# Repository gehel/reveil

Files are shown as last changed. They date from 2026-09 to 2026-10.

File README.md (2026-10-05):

# Réveil pour sourd

> **Statut : en cours de développement**

Réveil électronique custom conçu pour les personnes sourdes ou malentendantes. Au lieu d'une alarme sonore, le réveil utilise une LED clignotante et un moteur vibrant pour réveiller l'utilisateur.

## Matériel

### Microcontrôleur
- **Raspberry Pi Pico W** (RP2040) — firmware CircuitPython

### Affichages
- **2× MAX7219** pilotant 4 affichages 7-segments de 4 chiffres chacun :
  - Affichage de la date (jour/mois)
  - Affichage de l'année
  - Affichage de l'heure courante
  - Affichage de l'heure d'alarme

### Contrôles

| Composant | Rôle |
|---|---|
| 3× encodeurs rotatifs | Réglage de la date/année, de l'heure, et de l'alarme |
| Bouton poussoir | Arrêt de l'alarme |
| Interrupteur SPDT | Activation / désactivation de l'alarme |
| Bouton poussoir | Allumage des affichages et LED (extinction automatique après 30 s d'inactivité) |
| Potentiomètre | Réglage de la luminosité des affichages 7-segments |

### Alarme
- **LED** blanche (D1) clignotante, pilotée via un transistor Q1 (2N3904)
- **Moteur DC** piloté via un MOSFET (Q2) pour faire vibrer le lit — **IRLB8721PbF** (logic-level) dans le schéma/PCB, avec une résistance de grille R5 (100 Ω) ; la carte physique a encore l'ancien **IRF510** sans résistance de grille, rework pas encore fait (voir TODO)

### Alimentation
- Port **USB** du Raspberry Pi Pico
- **Barrel jack** 5 V (alternatif)

## Fichiers KiCad

Les fichiers source KiCad sont à la racine du projet :

| Fichier | Contenu |
|---|---|
| `reveil.kicad_sch` | Schématique racine |
| `heure_alarme.kicad_sch` | Feuille *Heure et Alarme* |
| `date.kicad_sch` | Feuille *Date* |
| `reveil.kicad_pcb` | Layout PCB |
| `fp-lib-table` | Table de librairies de footprints du projet (référence `reveil.pretty/`) |
| `reveil.pretty/` | Librairie locale de footprints corrigés (overrides de footprints système erronés — voir TODO) |

### Générer les fichiers Gerber avec KiBot

Les fichiers de fabrication (Gerber, BOM, positions) sont générés via [KiBot](https://github.com/INTI-CMNB/KiBot) à partir de `config.kibot.yaml`. `kibot` nécessite `wxPython` (pas de wheel précompilé sur toutes les plateformes) — utiliser le conteneur Docker de la CI plutôt qu'un `pip install` local :

```bash
docker run --rm -v "$PWD":/mnt -w /mnt ghcr.io/inti-cmnb/kicad9_auto_full:latest kibot -c config.kibot.yaml
```

`kicad-cli` (ERC/DRC en ligne de commande) est fourni par l'installation KiCad elle-même — via le snap, il est accessible en `/snap/bin/kicad.kicad-cli` (pas `kicad-cli` directement sur le PATH).

Les fichiers générés se trouvent dans le dossier `Generated/`. Les fichiers prêts pour JLCPCB sont dans `jlcpcb/`.

### Skills Claude Code (kicad-happy)

Les skills [kicad-happy](https://github.com/aklofas/kicad-happy) (analyse schéma/PCB, BOM, datasheets, EMC, SPICE, fournisseurs JLCPCB/LCSC/DigiKey/Mouser…) sont installés au niveau du projet via [`skills`](https://github.com/vercel-labs/skills) :

```bash
npx skills add aklofas/kicad-happy
```

Seul `skills-lock.json` (sources et hashes des skills) est versionné ; les fichiers installés (`.agents/skills/`, et les liens symboliques `.claude/skills/`) sont ignorés par git. Pour les restaurer après un clone, ou les mettre à jour :

```bash
npx skills experimental_install   # restaure les skills depuis skills-lock.json
npx skills update -p               # met à jour les skills du projet (et skills-lock.json)
```

## Connexions (RP2040)

| GPIO | Composant | Signal |
|---|---|---|
| GP0  | Encodeur *Heure* | A |
| GP1  | Encodeur *Heure* | B |
| GP2  | Encodeur *Heure* | SW (bouton) |
| GP3  | Encodeur *Date/Année* | A |
| GP4  | Encodeur *Date/Année* | B |
| GP5  | MAX7219 *Heure/Alarme* | CS (LOAD) |
| GP6  | MAX7219 *Heure/Alarme* | CLK |
| GP7  | MAX7219 *Heure/Alarme* | DIN |
| GP8  | Encodeur *Date/Année* | SW (bouton) |
| GP9  | MAX7219 *Date/Année* | CS (LOAD) |
| GP10 | MAX7219 *Date/Année* | CLK |
| GP11 | MAX7219 *Date/Année* | DIN |
| GP12 | Encodeur *Alarme* | A |
| GP13 | Encodeur *Alarme* | B |
| GP14 | Encodeur *Alarme* | SW (bouton) |
| GP15 | Bouton allumage affichages | Signal |
| GP16 | Bouton arrêt alarme | Signal |
| GP17 | LED alarme | Signal |
| GP18 | MOSFET moteur DC (Q2) | Gate |
| GP19 | Interrupteur SPDT alarme | Signal |
| GP26 | Potentiomètre luminosité | ADC |

## Logiciel

Firmware écrit en **CircuitPython**. Point d'entrée : `firmware/code.py`. La logique est dans `firmware/reveil/` :
- `firmware/reveil/display.py` — pilotage des 2 puces MAX7219 (classe `Afficheurs`)
- `firmware/reveil/encoder.py` — encodeur rotatif + bouton associé (classe `Encodeur`)
- `firmware/reveil/reglage_date.py` — logique pure du réglage date/année (cycle de modes, calcul des jours par mois, application d'une rotation) : aucune dépendance matérielle, testable directement sur l'hôte
- `firmware/reveil/reglage_heure.py` — logique pure du réglage heure (cycle de modes, application d'une rotation sur heures/minutes) : même principe que `reglage_date.py`, réutilisé tel quel pour l'heure d'alarme
- `firmware/reveil/luminosite.py` — lecture du potentiomètre LUMINOSITE (classe `Potentiometre`) + conversion pure ADC→niveau MAX7219 (`niveau_depuis_adc()`)

`display.py`, `encoder.py` et `luminosite.py` séparent la construction matérielle (`depuis_broches()`/`depuis_broche()`, qui importent `board`/`busio`/`digitalio`/`rotaryio`/`analogio`) du reste de la classe, qui reçoit ses dépendances déjà construites — ça permet de tester leur logique (calcul de delta, détection de clic, écriture des digits, conversion ADC) avec de faux objets, sans Pico ni stubs CircuitPython. `code.py` déploie via ces méthodes ; les tests injectent de faux capteurs/chips (voir `firmware/tests/`).

`make deploy` copie `firmware/code.py` et aplatit `firmware/reveil/*.py` à la racine de `CIRCUITPY` (CircuitPython ne cherche les modules qu'à la racine et dans `lib/`, pas dans un sous-dossier arbitraire du dépôt).

### Mode de fonctionnement

**Affichages DATE et ANNEE.** En fonctionnement normal, l'affichage DATE montre le jour et le mois courants au format `JJ.MM` (point décimal séparateur entre les deux), et l'affichage ANNEE montre l'année sur 4 chiffres. Les valeurs viennent de l'horloge interne du RP2040 (module CircuitPython `rtc`) : celle-ci n'a **pas de pile de sauvegarde** sur cette carte, donc elle repart d'une date par défaut (1er janvier de l'année courante de développement) à chaque reset ou coupure d'alimentation — elle doit être réglée à nouveau à chaque démarrage.

**Réglage via l'encodeur REGLAGE_DATE.** Un clic sur le bouton de l'encodeur fait entrer/avancer dans le cycle de réglage :

1. Appui 1 → mode **réglage du jour** : le champ jour clignote (~1,25 Hz), tourner l'encodeur l'incrémente/décrémente (boucle 1 → dernier jour du mois → 1, en tenant compte des mois à 30/31 jours et des années bissextiles).
2. Appui 2 → mode **réglage du mois** : le champ mois clignote, rotation = incrément/décrément (boucle 1-12). Si le jour courant n'existe pas dans le nouveau mois (ex. 31 → février), il est ramené au dernier jour valide.
3. Appui 3 → mode **réglage de l'année** : l'affichage ANNEE clignote en entier, rotation = incrément/décrément (boucle 2000-2099). Même ajustement du jour si nécessaire (29 février d'une année non bissextile).
4. Appui 4 → retour au mode **normal** (plus aucun champ ne clignote), le cycle recommence au prochain clic.

Chaque changement de valeur est appliqué immédiatement à l'horloge RTC (pas de bouton "valider" séparé).

**Affichage HEURE.** En fonctionnement normal, montre l'heure courante au format `HH.MM` (point décimal séparateur). Même horloge RTC que DATE/ANNEE (pas de pile de sauvegarde, à régler à chaque démarrage).

**Réglage via l'encodeur REGLAGE_HEURE.** Cycle à 3 états (un champ de moins que REGLAGE_DATE, pas d'équivalent de l'année) :

1. Appui 1 → mode **réglage des heures** : le champ heures clignote, rotation = incrément/décrément (boucle 0-23).
2. Appui 2 → mode **réglage des minutes** : le champ minutes clignote, rotation = incrément/décrément (boucle 0-59).
3. Appui 3 → retour au mode **normal**, le cycle recommence au prochain clic.

Même principe que REGLAGE_DATE : chaque changement est appliqué immédiatement à l'horloge RTC.

**Affichage ALARME.** Montre l'heure d'alarme réglée, au format `HH.MM`. Contrairement à DATE/ANNEE/HEURE, ce n'est **pas** une valeur RTC : juste une paire (heures, minutes) gardée en mémoire côté firmware, réinitialisée à une valeur par défaut (7h00) à chaque démarrage — comme pour l'heure courante, il n'y a pas de pile de sauvegarde.

**Réglage via l'encodeur REGLAGE_ALARME.** Même cycle à 3 états que REGLAGE_HEURE (réglage des heures puis des minutes de l'alarme, mêmes bornes 0-23/0-59), avec les mêmes fonctions de logique (`reglage_heure.py` est réutilisé tel quel : une paire heures/minutes avec un cycle de réglage à 2 champs, que ce soit l'heure courante ou l'heure d'alarme).

**L'alarme ne se déclenche pas encore** : pas de comparaison avec l'heure courante, pas de pilotage de la LED ni du moteur. Seule l'heure d'alarme peut être affichée et réglée pour l'instant.

**Luminosité via le potentiomètre LUMINOSITE.** Lu en continu (à chaque itération de la boucle principale) et appliqué aux deux puces MAX7219 (donc aux 4 affichages). La valeur ADC brute (0-65535) est convertie en niveau MAX7219 (0-15) par `luminosite.niveau_depuis_adc()`.

**Pas encore géré par ce firmware** : déclenchement de l'alarme (LED, moteur), bouton d'allumage des affichages, bouton d'arrêt alarme, interrupteur SPDT — voir TODO.

### Dépendances

Les bibliothèques CircuitPython nécessaires sont listées dans `firmware/requirements.txt` :

```
adafruit_max7219
```

Copier les bibliothèques dans le dossier `lib/` du Pico (accessible en mode stockage USB), ou via `make deps` (voir `firmware/Makefile`).

## TODO

### Problèmes matériels connus
- [x] ~~Court-circuit GND/+3V3 via l'interrupteur `ALARME_ON_OFF1` : le footprint système (`Button_Switch_THT:SW_Slide-03_Wuerth-WS-SLTV...`) avait les pads 1 et 2 physiquement inversés par rapport au composant monté.~~ Corrigé via une librairie locale `reveil.pretty/` (pads 1/2 échangés) + `fp-lib-table`. Vérifié par mesure au multimètre, ERC et DRC (voir historique git).
- [x] ~~LED D1 toujours allumée faiblement au lieu de clignoter : la base de Q1 (2N3904, driver de D1) était câblée directement sur GP17 sans résistance série, empêchant GP17 d'atteindre un état haut propre (chargé par la jonction base-émetteur).~~ Corrigé dans KiCad : ajout de **R4 = 1.5 kΩ** en série sur la base, et **R3 = 100 Ω** (au lieu de 47 kΩ, qui aurait quasi éteint la LED) pour ~16 mA dans D1 (LED blanche, Vf≈3.2V supposé — pas de référence/datasheet exacte pour D1, à vérifier si besoin de précision). Vérifié par ERC/DRC.
  - [ ] **Bloquant pour tester la LED** : le PCB physique existant n'a pas ces corrections (footprint switch + R3/R4) — il faut ressouder à la main (bodge) ou fabriquer un nouveau PCB avant de pouvoir tester `code.py` avec `board.LED` remplacé par `board.GP17`. `firmware/code.py` a été remis à `board.LED` (LED embarquée du Pico) en attendant.
- [x] ~~**Décalage schéma/carte physique — Q2 (moteur DC)** : le schéma KiCad indiquait un IRF540N, mais le MOSFET réellement monté sur le PCB physique était un IRF510.~~ Résolu en remplaçant Q2 par un **IRLB8721PbF** (logic-level) dans le schéma et le PCB — voir point suivant, qui couvre aussi la raison de ce changement. Footprint `TO-220-3_Horizontal_TabDown` (corrigé après repérage d'une variante `TO-220F` erronée), pinout G/D/S broches 1/2/3 vérifié contre la convention IR/Infineon. Vérifié par ERC/DRC.
- [x] ~~**Pilotage de grille de Q2 (moteur DC)** : topologie de câblage correcte (Gate←GP18, Drain→moteur(-), Source→GND, moteur(+)→VBUS ; vérifié via l'analyse du netlist). Le problème identifié :~~
  - GP18 pilote la grille de Q2 directement en 3.3V, sans résistance de grille ni driver dédié.
  - Ni l'IRF540N (ancien schéma) ni l'IRF510 (carte physique) ne sont des MOSFET **"logic-level"** : leur Rds(on) nominal est spécifié à Vgs=10V (IRF510 : ~0.54Ω max ; IRF540N : ~44-77 mΩ). À 3.3V (Vgs proche du seuil typique 2-4V de ces composants), le MOSFET risque de ne pas être pleinement enhancé → Rds(on) effectif bien plus élevé que la valeur datasheet → échauffement de Q2 et/ou sous-alimentation du moteur.
  - Corrigé dans KiCad : Q2 remplacé par un **IRLB8721PbF** (Vgs(th) ≈ 1-2V, pleinement enhancé dès Vgs≈2.5V, Rds(on) ≈ 8.7 mΩ typique à Vgs=4.5V — largement suffisant en pilotage direct 3.3V), plus ajout de **R5 = 100 Ω** en série sur la grille (limite le pic de courant transitoire vu par GP18 et amortit le ringing). Vérifié par ERC/DRC.
  - [ ] **Bloquant pour tester le moteur** : le PCB physique existant a encore l'ancien IRF510 sans R5 — il faut ressouder à la main (bodge) ou fabriquer un nouveau PCB avant de pouvoir tester le moteur avec ce circuit. Un moteur de test n'est de toute façon pas encore disponible.

### Améliorations matérielles proposées (revue schéma/PCB du 2026-10-03)

État au moment de la revue : ERC 0 erreur / 0 avertissement ; DRC 0 piste non connectée, 0 écart schéma/PCB, seulement 6 avertissements de sérigraphie de J2 coupée par le bord (normal pour un jack en bordure). Limite de la revue : aucun composant n'a de MPN ni de datasheet dans le projet, les valeurs datasheet citées ci-dessous n'ont pas été relues dans les PDF.

**Prioritaire**
- [x] ~~**Symbole des afficheurs incohérent avec le câblage** : le schéma utilisait `CA56-12EWA` (anode commune), mais les anodes communes CA1-CA4 sont reliées aux sorties `DIG_x` du MAX7219 (qui *absorbent* le courant) et les segments aux sorties `SEG_x` (qui *fournissent* le courant). Avec de vrais afficheurs à anode commune, rien ne s'allumerait ; comme les afficheurs fonctionnent, les composants montés sont très probablement à cathode commune (confirmé par le fonctionnement du circuit, référence imprimée non relue).~~ → Symbole remplacé par `CC56-12EWA` (même brochage/footprint `Display_7Segment:CA56-12EWA`, seules la doc et la BOM changent) dans `date.kicad_sch`, `heure_alarme.kicad_sch` et la `Value` des empreintes dans `reveil.kicad_pcb`. BOM/CPL JLCPCB (`jlcpcb/production_files/`) encore à régénérer via `kibot -c config.kibot.yaml` (kibot non disponible dans cet environnement).
- [x] ~~**Pas de diode de roue libre sur le moteur** : rien entre le drain de Q2 et VBUS, en parallèle de M1. La surtension inductive à chaque coupure passe par l'avalanche de Q2 et parasite le 5 V du Pico.~~ → Ajouté en schéma : D2 (Schottky 1N5819, cathode côté VBUS, anode côté drain de Q2) et C5 (100 nF) en parallèle de M1. Reste à faire : `update PCB from schematic` et placement manuel des empreintes D2/C5 sur le PCB avant fabrication (pas d'empreinte existante pour ces deux nouveaux composants).
- [x] ~~**Grille de Q2 flottante au démarrage** : GPIO18 est en haute impédance pendant le boot/reset → vibration intempestive possible, ou Q2 à moitié passant qui chauffe.~~ → Ajouté R6 (100 kΩ) entre grille et source de Q2, près de Q2 ; ajouté aussi R7 (47 kΩ) entre base et émetteur de Q1, pour garder Q1 déterministement bloqué. Empreintes placées et routées sur le PCB.
- [x] ~~**R1 sans valeur** (valeur « R ») : c'est la résistance ISET de U2.~~ → Mis à 47 kΩ comme R2 (≈ 14 mA par segment), sinon HEURE/ALARME n'auraient pas eu la même luminosité que DATE/ANNEE.

**Alimentation**
- [x] ~~**Le barrel jack J1 alimente directement VBUS** : si l'USB est branché en même temps, les deux 5 V sont en parallèle et l'alimentation du jack renvoie du courant vers le PC.~~ → Ajouté en schéma/PCB : **D3** (Schottky 1N5822, anode côté jack, cathode côté rail) et **C6** (220 µF) en entrée du jack, le rail résultant renommé **VSYS** (branché sur la broche VSYS/39 du Pico, plus sur VBUS/40). Tout ce qui était sur l'ancien net VBUS (MAX7219 U1/U2, moteur, LED, D2) est maintenant sur VSYS ; la broche VBUS du Pico (40) n'est plus connectée côté carte, elle ne sert plus qu'à l'alimentation USB du Pico lui-même. Vérifié par analyse du schéma et du netlist PCB (kibot non disponible dans cet environnement, DRC/ERC à relancer avant fabrication). Reste à faire : pas de protection contre l'inversion de polarité du jack ; le PCB physique existant n'a ni D3 ni C6 (nouveau PCB ou bodge nécessaire avant de tester l'alimentation par jack).
- [ ] **Logique 3,3 V vers un MAX7219 alimenté en 5 V** : le VIH minimal du MAX7219 est de 3,5 V, les signaux du Pico sont hors spécification (ça marche, mais sans marge). → 74AHCT125 ou 74HCT245 alimenté en 5 V sur DIN/CLK/LOAD (6 signaux).
- [ ] **Découplage des MAX7219 trop loin** (datasheet : 10 µF + 100 nF au plus près de V+/GND). Distances estimées depuis la broche V+ : U1 → C1 ≈ 21 mm, C2 ≈ 30 mm ; U2 → C3 ≈ 12 mm, C4 ≈ 15 mm. → Rapprocher à moins de 5 mm (le balayage du MAX7219 crée de forts pics de courant).

**PCB**
- [ ] Toutes les pistes font 0,2 mm, alimentations comprises. → Passer VBUS, GND et le chemin moteur (drain de Q2) à 0,5-1 mm.
- [ ] Plan de masse B.Cu très découpé par les pistes de signal. → Ajouter des vias de couture GND, router moins en B.Cu.
- [x] ~~VIBREUR fait ≈ 169 mm entre le Pico et Q2.~~ → Garder R5 et la future résistance de rappel près de Q2 (déjà le cas pour R5). C'est fait : R5 (~20 mm de Q2) et R6 (~5.5 mm de Q2, ajoutée avec la correction de la grille flottante) sont les deux près de Q2 ; les 169 mm sont juste le signal GP18 brut entre le Pico et R5, sans caractère critique.
- [ ] Cartouche vide (titre, révision, date) sur le schéma et le PCB. → Le remplir (les sorties KiBot en profitent).
- [ ] Ajouter des points de test (voir section suivante).

**Fonctionnel**
- [ ] **Aucune sauvegarde de l'heure** : une coupure de courant efface l'heure et l'alarme, ce qui est critique pour un réveil. → DS3231 + pile CR2032 sur I2C (GP20/GP21 sont libres), et/ou synchronisation NTP par le WiFi du Pico W (firmware seul).
- [ ] **Une LED 3 mm (~16 mA) réveille mal.** → LED de puissance ou ruban LED commandé par un MOSFET, comme le moteur.
- [ ] **Moteur sur un jack 3,5 mm avec le +5 V sur le manchon** (exposé). → Connecteur polarisé et verrouillable (JST-XH, bornier).
- [x] ~~Pour M1, cocher « Exclure du PCB » plutôt que de laisser l'empreinte vide.~~ Déjà fait : M1 a `on_board no` dans le schéma et aucune empreinte dans le PCB.
- [x] ~~100 nF sur le curseur de LUMINOSITE, alimenté par ADC_VREF/AGND.~~ → Ajouté **C7** (100 nF) sur le curseur, et le haut du potentiomètre LUMINOSITE1 reconnecté sur **ADC_VREF** (broche du Pico, auparavant non connectée) au lieu de +3V3. Empreintes placées et routées sur le PCB.
- [x] ~~Bouton reset (RUN vers GND) pour le développement.~~ Pas voulu : décision du mainteneur, pas de bouton reset.
- [x] ~~Filtres RC pour les encodeurs EC11 (10 kΩ + 10 nF).~~ Pas nécessaire pour l'instant : les encodeurs fonctionnent suffisamment bien sans, à revoir si besoin plus tard.

**Faux positifs écartés par la revue** : 3V3_EN « sans pull-up » (pull-up interne au Pico), J2 « sans masse » (moteur commuté côté bas, voulu), absence de MPN (sans importance pour un montage à la main), J2 qui dépasse du bord (montage en bordure).

### Points de test proposés

Pastilles traversantes (`TestPoint:TestPoint_THTPad_D2.0mm_Drill1.0mm`) ou boucles (`TestPoint:TestPoint_Keystone_5000-5004_Miniature`) pour les masses, avec la référence `TPx` et le nom du net sur la sérigraphie. À placer en bord de carte ou dans les zones dégagées, accessibles avec les afficheurs et les encodeurs montés.

| Point | Net | Usage |
|---|-----|---|
| TP1, TP2, TP3 | GND | Masse pour la pince de l'oscilloscope / du multimètre : une près de J1, une près des MAX7219, une près de Q2 (boucles) |
| TP4 | VBUS (5 V, broche 40 du Pico) | Présent seulement si le Pico est alimenté par USB ; n'est plus relié au jack J1 (voir « Alimentation » ci-dessus) |
| TP5 | +3V3 | Sortie du régulateur du Pico |
| TP6 | VSYS | Tension d'entrée réelle (USB ou jack via D3), chute sous charge (moteur + afficheurs à fond) |
| TP7, TP8, TP9 | DATE_DIN, DATE_CLK, DATE_LOAD | Trame SPI vers U1 (niveaux logiques, décodage à l'analyseur logique) |
| TP10, TP11, TP12 | HEURE_ALARME_DIN, HEURE_ALARME_CLK, HEURE_ALARME_LOAD | Trame SPI vers U2 |
| TP13 | Grille de Q2 (après R5) | Commande du moteur, état au démarrage (vérifie la résistance de rappel) |
| TP14 | Drain de Q2 | Surtension de coupure du moteur (vérifie la diode de roue libre), Vds en conduction |
| TP15 | Collecteur de Q1 | Commande de la LED (saturation de Q1) |
| TP16 | LUMINOSITE | Tension du curseur du potentiomètre (bruit lu par l'ADC) |
| TP17 | ISET de U1 ou U2 | Optionnel : contrôle de la résistance ISET sans dessouder |

Les signaux des encodeurs, des boutons et de l'interrupteur restent accessibles directement sur les broches des composants, pas besoin de points de test dédiés.

### Structure du firmware
- [x] ~~`reveil/display.py`, `reveil/encoder.py`, `reveil/luminosite.py`~~ — modules matériels (MAX7219, encodeurs rotatifs, potentiomètre ADC), construction hardware isolée dans `depuis_broches()`/`depuis_broche()` pour rester testables par injection de dépendances
- [x] ~~`reveil/reglage_date.py`, `reveil/reglage_heure.py`~~ — logique métier des réglages date/année et heure, isolée (modules purs, sans import CircuitPython). `reglage_heure.py` est réutilisé tel quel pour l'heure d'alarme (même forme : une paire heures/minutes avec un cycle de réglage à 2 champs)
- [ ] `alarm.py` — déclenchement de l'alarme (comparaison heure courante / heure d'alarme réglée, pilotage LED + moteur) pas encore implémenté ; l'heure d'alarme peut déjà être affichée et réglée
- [ ] `backlight.py` — extinction automatique des affichages après 30 s d'inactivité pas encore implémentée (luminosité l'est déjà via `luminosite.py`, mais l'allumage/extinction sur bouton est distinct)
- [ ] Isoler la logique métier restante (déclenchement alarme, extinction auto) au fur et à mesure qu'elle est écrite, sur le même modèle que `reglage_date.py`

### Déploiement (Makefile)
- [x] ~~Créer un `Makefile` (`firmware/Makefile`) avec les cibles :~~
  - `make install-circuitpython` — flashe CircuitPython sur le Pico
  - `make deploy` — copie `code.py` et aplatit `reveil/*.py` à la racine du volume `CIRCUITPY` monté par l'hôte (pas `mpremote fs cp`, qui échoue en lecture seule sur CircuitPython)
  - `make deps` — installe les dépendances CircuitPython via `circup`
  - [x] ~~`make test-unit`~~ — lance les tests unitaires sur l'hôte (`pytest tests/`)
  - [ ] `make test-integration` — lance les tests d'intégration sur le Pico via `mpremote run` (cible stub, pas encore exécutable)
- [x] ~~Séparer les dépendances~~ : `firmware/requirements.txt` (librairies CircuitPython installées sur le Pico via `circup`, ce n'est pas un fichier pip) vs `requirements-dev.txt` à la racine (outillage hôte : `circup`, `pytest`, stubs d'autocomplete ; `kibot` nécessite Docker, voir commentaire dans le fichier)
- [ ] Envisager une migration vers Poetry (ou un outil équivalent) pour `requirements-dev.txt` si le besoin de lockfile reproductible ou de gestion d'environnement plus poussée se fait sentir — pas nécessaire pour l'instant (projet hobby solo, peu de dépendances)

### Tests unitaires (sur hôte)
- [x] ~~Mettre en place `pytest`~~ (`firmware/pytest.ini`, `firmware/tests/`, lancés via `make test-unit`)
- [x] ~~Écrire des stubs pour les modules CircuitPython~~ — évité par un autre moyen : `display.py`/`encoder.py`/`luminosite.py` séparent la construction matérielle (`depuis_broches()`/`depuis_broche()`) du reste de la classe, qui reçoit ses dépendances déjà construites (`board`/`busio`/`digitalio`/`rotaryio`/`analogio` ne sont importés que dans ces méthodes) ; les tests injectent de faux objets (voir `firmware/tests/test_display.py`, `test_encoder.py`, `test_luminosite.py`) sans avoir besoin de stubber les modules CircuitPython eux-mêmes
  - **Piège rencontré** : `firmware/code.py` (imposé par CircuitPython comme nom de point d'entrée) entre en collision avec le module standard `code` — si `firmware/` se retrouve dans `sys.path` (ex. `python -m pytest`, qui ajoute le répertoire courant), l'import de `code` par `pdb` récupère `firmware/code.py` à la place et plante. D'où `firmware/reveil/` comme dossier séparé pour la logique importable, et `pytest` invoqué directement (jamais `python -m pytest`) dans le Makefile.
- [x] ~~Écrire les tests unitaires pour la logique métier des réglages date/année et heure (`firmware/tests/test_reglage_date.py`, `test_reglage_heure.py`, réutilisés pour l'heure d'alarme) et pour la conversion ADC→luminosité (`test_luminosite.py`)~~ ; reste à faire au fur et à mesure pour le déclenchement de l'alarme, l'extinction automatique
- [x] ~~Test de régression sur la position physique 4-7 de la puce Heure/Alarme (`test_display.py::test_heure_et_alarme_ne_se_marchent_pas_dessus`)~~ — même classe de bug que l'inversion des digits déjà rencontrée sur Date/Année, jamais testée explicitement sur cette puce avant l'ajout d'ALARME

### Tests d'intégration (sur Pico)
- [ ] Ajouter `adafruit_unittest` aux dépendances
- [ ] Écrire les tests d'intégration pour chaque composant hardware
- [ ] Intégrer l'exécution via `mpremote run` dans le `Makefile`

## Licence

Matériel : [CERN Open Hardware Licence Version 2 - Strongly Reciprocal (CERN-OHL-S)](https://ohwr.org/cern_ohl_s_v2.txt)

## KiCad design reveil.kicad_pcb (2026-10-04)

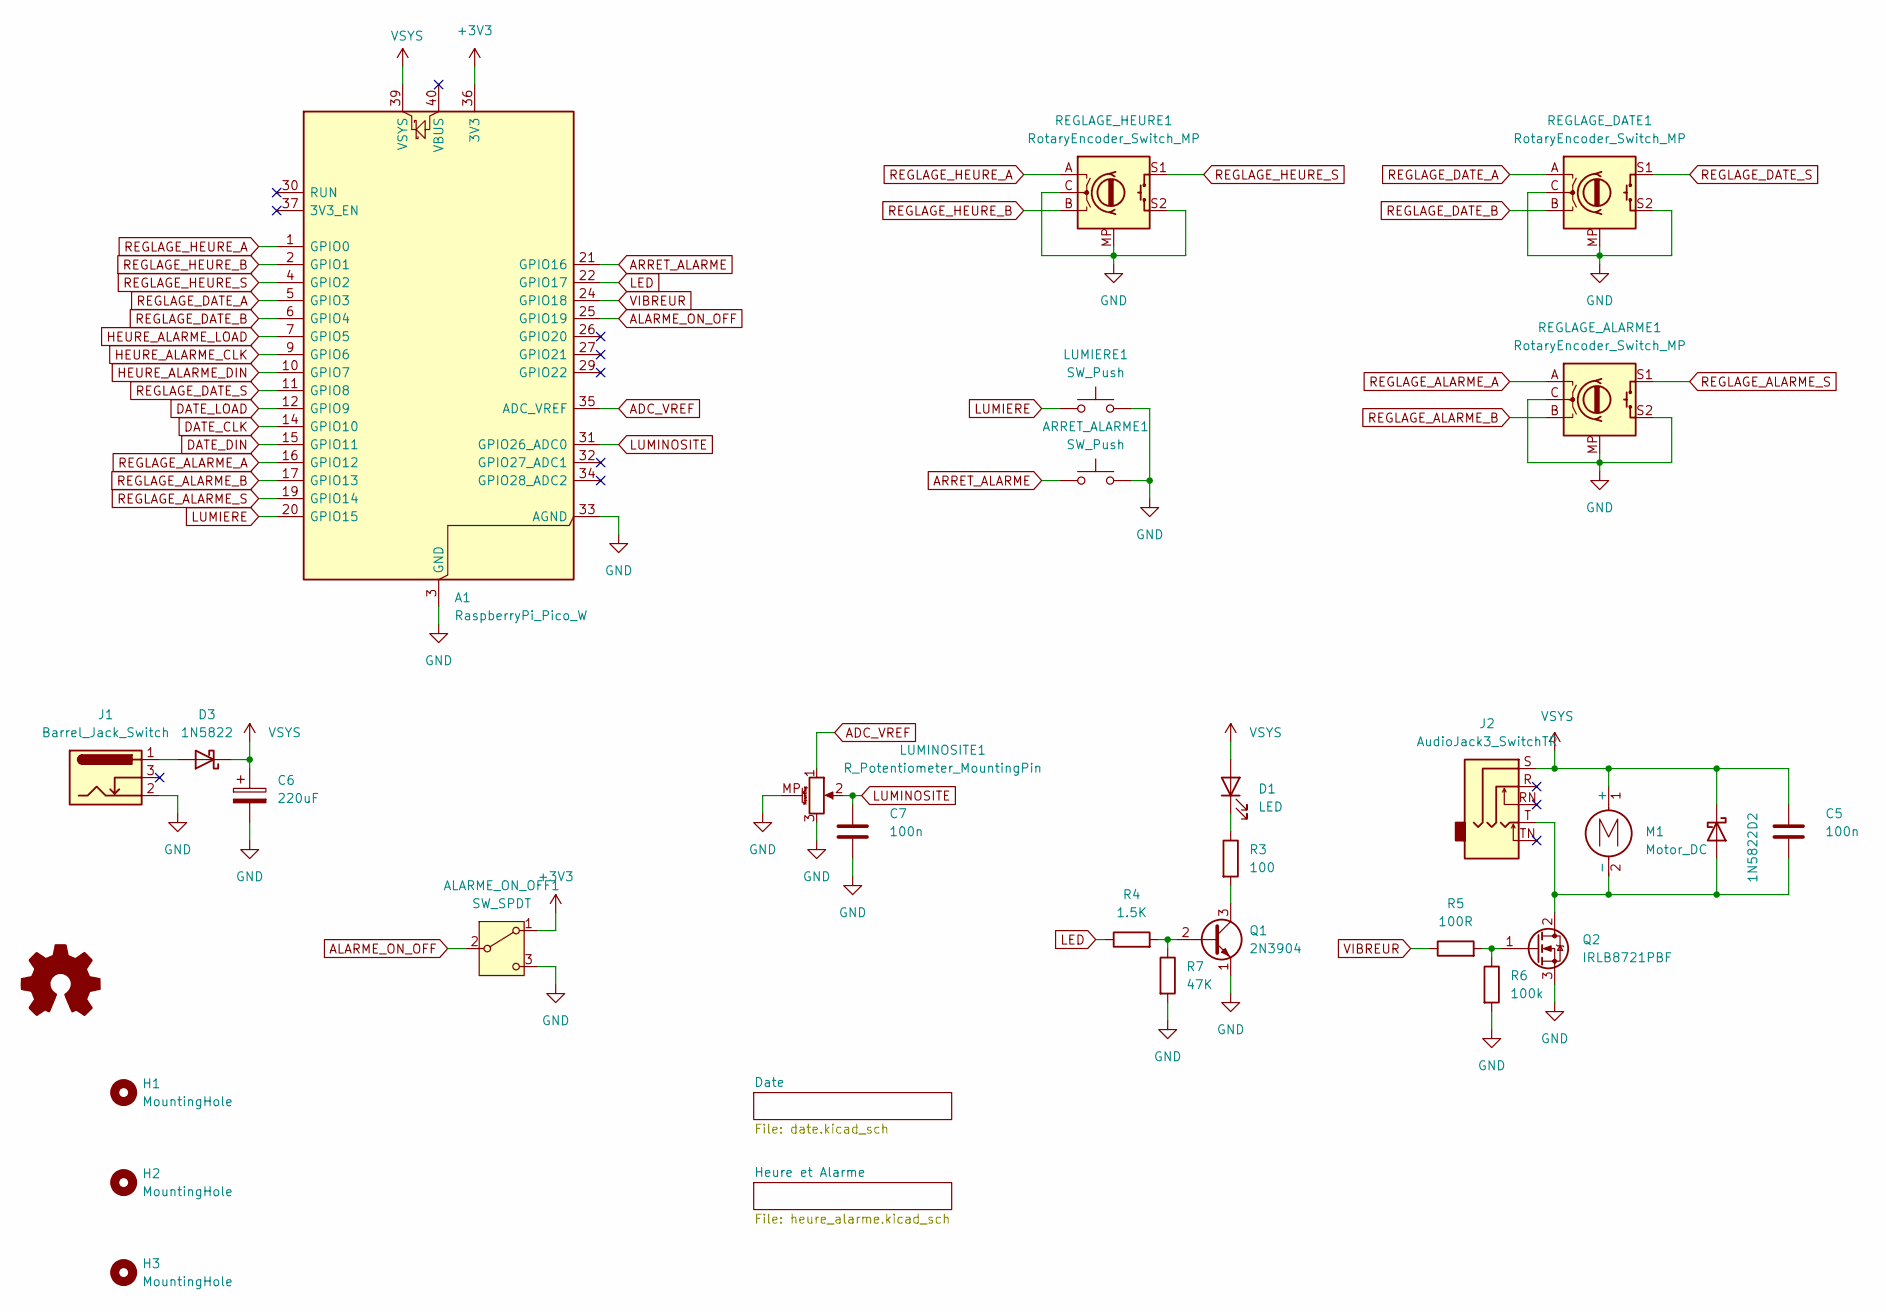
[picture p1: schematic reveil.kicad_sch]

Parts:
A1: RaspberryPi_Pico_W; RaspberryPi_Pico_Common_THT
ALARME_ON_OFF1: SW_SPDT; SW_Slide-03_Wuerth-WS-SLTV_10x2.5x6.4_P2.54mm
ARRET_ALARME1: SW_Push; SW_PUSH_6mm
C5, C7: 100n; C_Disc_D3.0mm_W1.6mm_P2.50mm
C6: 220uF; CP_Radial_D7.5mm_P2.50mm
D1: LED; LED_D3.0mm
D2, D3: 1N5822; D_DO-41_SOD81_P10.16mm_Horizontal
H1, H2, H3: MountingHole; MountingHole_4.3mm_M4
J1: Barrel_Jack_Switch; BarrelJack_Wuerth_6941xx301002
J2: AudioJack3_SwitchTR; Jack_3.5mm_CUI_SJ1-3525N_Horizontal
LUMIERE1: SW_Push; SW_PUSH_6mm
LUMINOSITE1: R_Potentiometer_MountingPin; Potentiometer_Bourns_PTV09A-1_Single_Vertical
M1: Motor_DC
Q1: 2N3904; TO-92_HandSolder
Q2: IRLB8721PBF; TO-220-3_Horizontal_TabDown
R3: 100; R_Axial_DIN0207_L6.3mm_D2.5mm_P7.62mm_Horizontal
R4: 1.5K; R_Axial_DIN0207_L6.3mm_D2.5mm_P7.62mm_Horizontal
R5: 100R; R_Axial_DIN0207_L6.3mm_D2.5mm_P7.62mm_Horizontal
R6: 100k; R_Axial_DIN0207_L6.3mm_D2.5mm_P7.62mm_Horizontal
R7: 47K; R_Axial_DIN0207_L6.3mm_D2.5mm_P7.62mm_Horizontal
REGLAGE_ALARME1: RotaryEncoder_Switch_MP; RotaryEncoder_Alps_EC11E-Switch_Vertical_H20mm_MountingHoles
REGLAGE_DATE1: RotaryEncoder_Switch_MP; RotaryEncoder_Alps_EC11E-Switch_Vertical_H20mm_MountingHoles
REGLAGE_HEURE1: RotaryEncoder_Switch_MP; RotaryEncoder_Alps_EC11E-Switch_Vertical_H20mm_MountingHoles

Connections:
+3V3: A1.36 (3V3), ALARME_ON_OFF1.1 (A)
ADC_VREF: A1.35 (ADC_VREF), LUMINOSITE1.1
ALARME_ON_OFF: A1.25 (GPIO19), ALARME_ON_OFF1.2 (B)
ARRET_ALARME: A1.21 (GPIO16), ARRET_ALARME1.1
DATE_CLK: A1.14 (GPIO10); also elsewhere on the board
DATE_DIN: A1.15 (GPIO11); also elsewhere on the board
DATE_LOAD: A1.12 (GPIO9); also elsewhere on the board
GND: A1.3 (GND), A1.8 (GND), A1.13 (GND), A1.18 (GND), A1.23 (GND), A1.28 (GND), A1.33 (AGND), A1.38 (GND), ALARME_ON_OFF1.3 (C), ARRET_ALARME1.2, C6.2, C7.2, J1.2, LUMIERE1.2, LUMINOSITE1.3, LUMINOSITE1.MP (MountPin), Q1.1 (E), Q2.3 (S), R6.2, R7.2, REGLAGE_ALARME1.C, REGLAGE_ALARME1.MP, REGLAGE_ALARME1.S2, REGLAGE_DATE1.C, REGLAGE_DATE1.MP, REGLAGE_DATE1.S2, REGLAGE_HEURE1.C, REGLAGE_HEURE1.MP, REGLAGE_HEURE1.S2; also elsewhere on the board
HEURE_ALARME_CLK: A1.9 (GPIO6); also elsewhere on the board
HEURE_ALARME_DIN: A1.10 (GPIO7); also elsewhere on the board
HEURE_ALARME_LOAD: A1.7 (GPIO5); also elsewhere on the board
LED: A1.22 (GPIO17), R4.1
LUMIERE: A1.20 (GPIO15), LUMIERE1.1
LUMINOSITE: A1.31 (GPIO26_ADC0), C7.1, LUMINOSITE1.2
unnamed: D1.1 (K), R3.1
unnamed: C5.2, D2.2 (A), J2.T, M1.2 (-), Q2.2 (D)
unnamed: D3.2 (A), J1.1
unnamed: Q1.2 (B), R4.2, R7.1
unnamed: Q1.3 (C), R3.2
unnamed: Q2.1 (G), R5.2, R6.1
REGLAGE_ALARME_A: A1.16 (GPIO12), REGLAGE_ALARME1.A
REGLAGE_ALARME_B: A1.17 (GPIO13), REGLAGE_ALARME1.B
REGLAGE_ALARME_S: A1.19 (GPIO14), REGLAGE_ALARME1.S1
REGLAGE_DATE_A: A1.5 (GPIO3), REGLAGE_DATE1.A
REGLAGE_DATE_B: A1.6 (GPIO4), REGLAGE_DATE1.B
REGLAGE_DATE_S: A1.11 (GPIO8), REGLAGE_DATE1.S1
REGLAGE_HEURE_A: A1.1 (GPIO0), REGLAGE_HEURE1.A
REGLAGE_HEURE_B: A1.2 (GPIO1), REGLAGE_HEURE1.B
REGLAGE_HEURE_S: A1.4 (GPIO2), REGLAGE_HEURE1.S1
VIBREUR: A1.24 (GPIO18), R5.1
VSYS: A1.39 (VSYS), C5.1, C6.1, D1.2 (A), D2.1 (K), D3.1 (K), J2.S, M1.1 (+); also elsewhere on the board

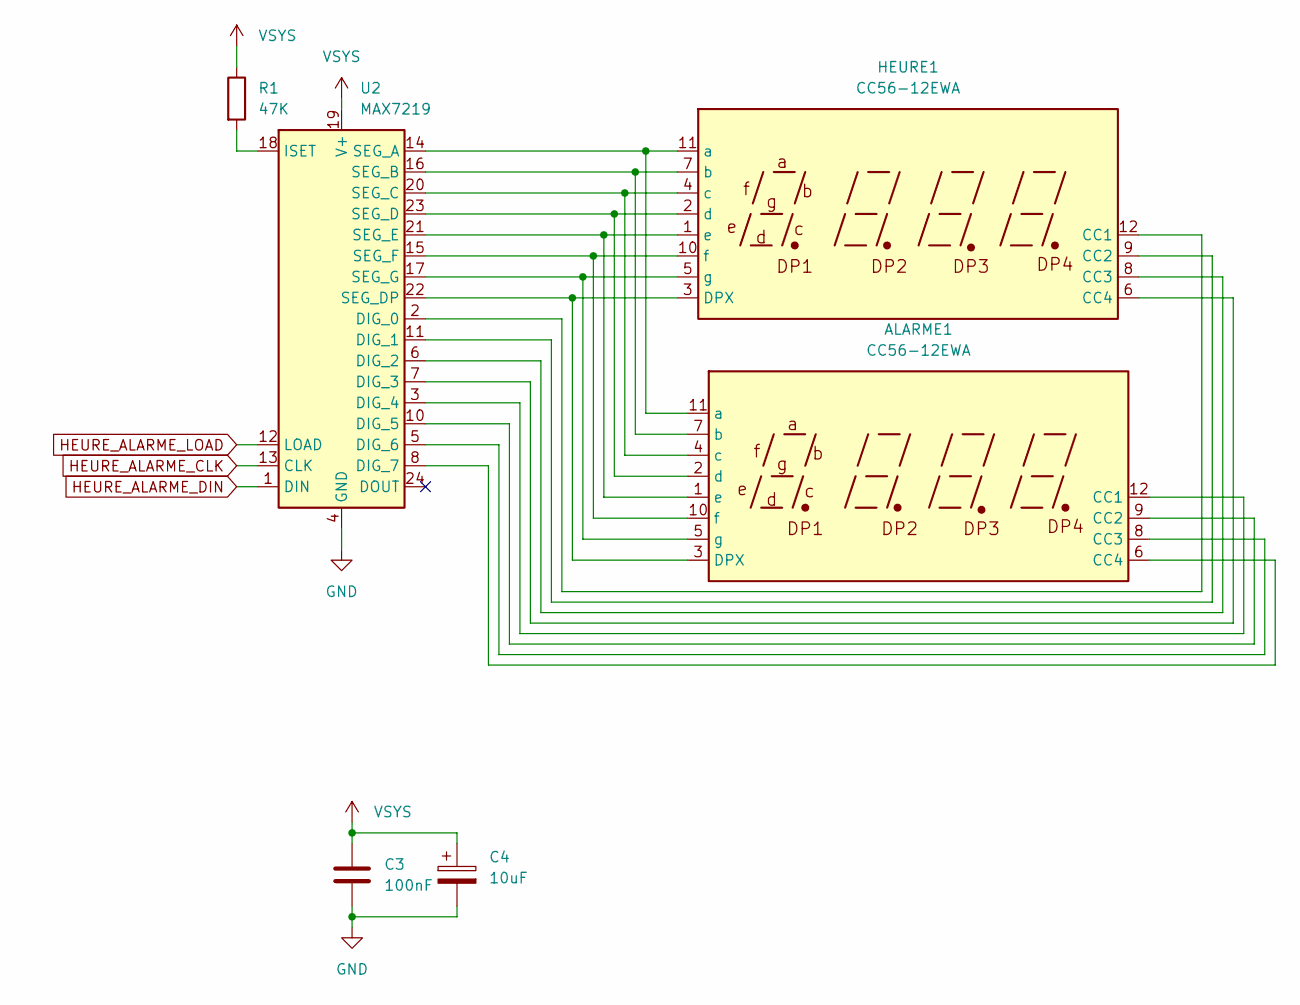
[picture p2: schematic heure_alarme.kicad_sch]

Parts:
ALARME1: CC56-12EWA; CA56-12EWA
C3: 100nF; C_Disc_D3.0mm_W1.6mm_P2.50mm
C4: 10uF; CP_Radial_D7.5mm_P2.50mm
HEURE1: CC56-12EWA; CA56-12EWA
R1: 47K; R_Axial_DIN0207_L6.3mm_D2.5mm_P7.62mm_Horizontal
U2: MAX7219; DIP-24_W7.62mm_Socket_LongPads

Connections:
GND: C3.2, C4.2, U2.4 (GND), U2.9 (GND); also elsewhere on the board
HEURE_ALARME_CLK: U2.13 (CLK); also elsewhere on the board
HEURE_ALARME_DIN: U2.1 (DIN); also elsewhere on the board
HEURE_ALARME_LOAD: U2.12 (LOAD); also elsewhere on the board
unnamed: ALARME1.12 (CC1), U2.3 (DIG_4)
unnamed: ALARME1.9 (CC2), U2.10 (DIG_5)
unnamed: ALARME1.8 (CC3), U2.5 (DIG_6)
unnamed: ALARME1.6 (CC4), U2.8 (DIG_7)
unnamed: ALARME1.3 (DPX), HEURE1.3 (DPX), U2.22 (SEG_DP)
unnamed: ALARME1.11 (a), HEURE1.11 (a), U2.14 (SEG_A)
unnamed: ALARME1.7 (b), HEURE1.7 (b), U2.16 (SEG_B)
unnamed: ALARME1.4 (c), HEURE1.4 (c), U2.20 (SEG_C)
unnamed: ALARME1.2 (d), HEURE1.2 (d), U2.23 (SEG_D)
unnamed: ALARME1.1 (e), HEURE1.1 (e), U2.21 (SEG_E)
unnamed: ALARME1.10 (f), HEURE1.10 (f), U2.15 (SEG_F)
unnamed: ALARME1.5 (g), HEURE1.5 (g), U2.17 (SEG_G)
unnamed: HEURE1.12 (CC1), U2.2 (DIG_0)
unnamed: HEURE1.9 (CC2), U2.11 (DIG_1)
unnamed: HEURE1.8 (CC3), U2.6 (DIG_2)
unnamed: HEURE1.6 (CC4), U2.7 (DIG_3)
unnamed: R1.2, U2.18 (ISET)
VSYS: C3.1, C4.1, R1.1, U2.19 (V+); also elsewhere on the board

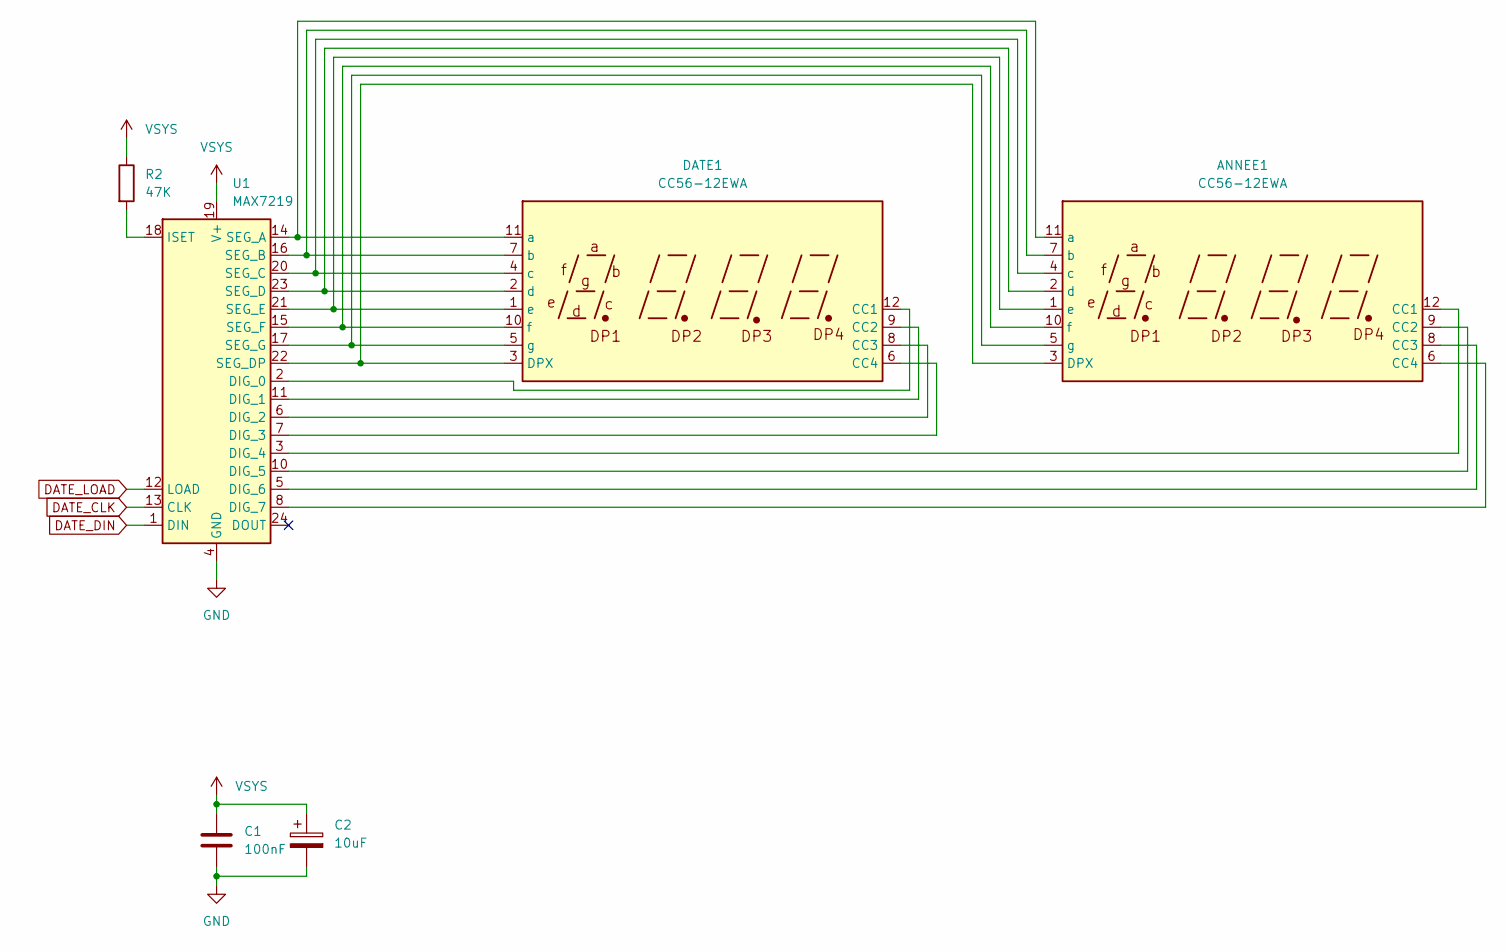
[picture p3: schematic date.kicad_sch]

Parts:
ANNEE1: CC56-12EWA; CA56-12EWA
C1: 100nF; C_Disc_D3.0mm_W1.6mm_P2.50mm
C2: 10uF; CP_Radial_D7.5mm_P2.50mm
DATE1: CC56-12EWA; CA56-12EWA
R2: 47K; R_Axial_DIN0207_L6.3mm_D2.5mm_P7.62mm_Horizontal
U1: MAX7219; DIP-24_W7.62mm_Socket_LongPads

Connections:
DATE_CLK: U1.13 (CLK); also elsewhere on the board
DATE_DIN: U1.1 (DIN); also elsewhere on the board
DATE_LOAD: U1.12 (LOAD); also elsewhere on the board
GND: C1.2, C2.2, U1.4 (GND), U1.9 (GND); also elsewhere on the board
unnamed: ANNEE1.12 (CC1), U1.3 (DIG_4)
unnamed: ANNEE1.9 (CC2), U1.10 (DIG_5)
unnamed: ANNEE1.8 (CC3), U1.5 (DIG_6)
unnamed: ANNEE1.6 (CC4), U1.8 (DIG_7)
unnamed: ANNEE1.3 (DPX), DATE1.3 (DPX), U1.22 (SEG_DP)
unnamed: ANNEE1.11 (a), DATE1.11 (a), U1.14 (SEG_A)
unnamed: ANNEE1.7 (b), DATE1.7 (b), U1.16 (SEG_B)
unnamed: ANNEE1.4 (c), DATE1.4 (c), U1.20 (SEG_C)
unnamed: ANNEE1.2 (d), DATE1.2 (d), U1.23 (SEG_D)
unnamed: ANNEE1.1 (e), DATE1.1 (e), U1.21 (SEG_E)
unnamed: ANNEE1.10 (f), DATE1.10 (f), U1.15 (SEG_F)
unnamed: ANNEE1.5 (g), DATE1.5 (g), U1.17 (SEG_G)
unnamed: DATE1.12 (CC1), U1.2 (DIG_0)
unnamed: DATE1.9 (CC2), U1.11 (DIG_1)
unnamed: DATE1.8 (CC3), U1.6 (DIG_2)
unnamed: DATE1.6 (CC4), U1.7 (DIG_3)
unnamed: R2.2, U1.18 (ISET)
VSYS: C1.1, C2.1, R2.1, U1.19 (V+); also elsewhere on the board

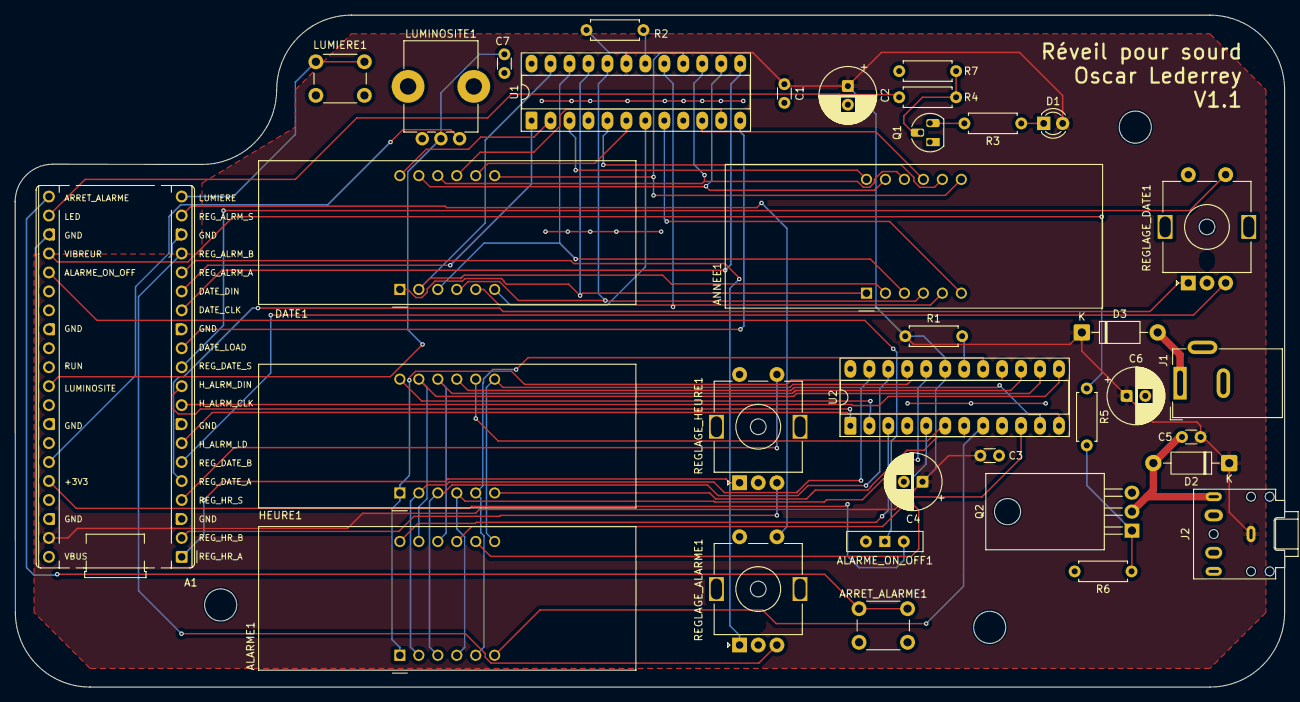
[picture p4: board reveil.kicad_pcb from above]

Board: 2 copper layers, 170.0 x 90.0 mm, 38 parts (0 on the bottom side), 65 nets.

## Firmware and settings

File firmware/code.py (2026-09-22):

"""Reveil pour sourd - firmware principal.

Pour le moment : affichages DATE, ANNEE, HEURE et ALARME + reglage via
les encodeurs REGLAGE_DATE, REGLAGE_HEURE et REGLAGE_ALARME, plus la
luminosite des affichages via le potentiometre LUMINOSITE. Voir le
README (section "Mode de fonctionnement") pour le comportement
detaille. L'alarme ne se declenche pas encore (pas de comparaison avec
l'heure courante, pas de LED/moteur) : seule l'heure d'alarme peut
etre affichee et reglee pour le moment.

La logique metier (reglage_date.py, reglage_heure.py) est testee
separement sur l'hote (firmware/tests/, `make test-unit`) ; ce fichier
ne fait qu'orchestrer le materiel autour d'elle. reglage_heure.py sert
a la fois pour l'heure courante et pour l'heure d'alarme : les deux
sont des paires (heures, minutes) avec les memes bornes (0-23/0-59) et
le meme cycle de reglage.
"""
import board
import rtc
import time

import reglage_date
import reglage_heure
from display import Afficheurs
from encoder import Encodeur
from luminosite import Potentiometre

ANNEE_DEFAUT = 2026
ALARME_HEURES_DEFAUT = 7
ALARME_MINUTES_DEFAUT = 0

afficheurs = Afficheurs.depuis_broches()
encodeur_date = Encodeur.depuis_broches(board.GP3, board.GP4, board.GP8)
encodeur_heure = Encodeur.depuis_broches(board.GP0, board.GP1, board.GP2)
encodeur_alarme = Encodeur.depuis_broches(board.GP12, board.GP13, board.GP14)
potentiometre = Potentiometre.depuis_broche(board.GP26)

# Horloge logicielle du RP2040 : pas de pile de sauvegarde sur cette carte,
# donc reinitialisee a une date/heure par defaut a chaque reset/coupure d'alim.
horloge = rtc.RTC()
horloge.datetime = time.struct_time((ANNEE_DEFAUT, 1, 1, 0, 0, 0, 0, 1, -1))

# L'heure d'alarme n'est pas geree par la RTC (ce n'est pas l'heure
# courante) : simple valeur locale, reinitialisee elle aussi a chaque
# demarrage.
alarme_heures: int = ALARME_HEURES_DEFAUT
alarme_minutes: int = ALARME_MINUTES_DEFAUT

mode_date: str = "NORMAL"
mode_heure: str = "NORMAL"
mode_alarme: str = "NORMAL"
print("Reglage date/annee : clic sur REGLAGE_DATE (jour -> mois -> annee -> normal)")
print("Reglage heure : clic sur REGLAGE_HEURE (heures -> minutes -> normal)")
print("Reglage alarme : clic sur REGLAGE_ALARME (heures -> minutes -> normal)")

while True:
    delta_date = encodeur_date.lire_delta()
    if encodeur_date.clic():
        mode_date = reglage_date.mode_suivant(mode_date)
        print(f"Mode date : {mode_date}")

    delta_heure = encodeur_heure.lire_delta()
    if encodeur_heure.clic():
        mode_heure = reglage_heure.mode_suivant(mode_heure)
        print(f"Mode heure : {mode_heure}")

    delta_alarme = encodeur_alarme.lire_delta()
    if encodeur_alarme.clic():
        mode_alarme = reglage_heure.mode_suivant(mode_alarme)
        print(f"Mode alarme : {mode_alarme}")

    maintenant = horloge.datetime
    jour, mois, annee = reglage_date.appliquer_rotation(
        mode_date, maintenant.tm_mday, maintenant.tm_mon, maintenant.tm_year, delta_date
    )
    heures, minutes = reglage_heure.appliquer_rotation(
        mode_heure, maintenant.tm_hour, maintenant.tm_min, delta_heure
    )
    alarme_heures, alarme_minutes = reglage_heure.appliquer_rotation(
        mode_alarme, alarme_heures, alarme_minutes, delta_alarme
    )

    if (jour, mois, annee, heures, minutes) != (
        maintenant.tm_mday,
        maintenant.tm_mon,
        maintenant.tm_year,
        maintenant.tm_hour,
        maintenant.tm_min,
    ):
        horloge.datetime = time.struct_time(
            (annee, mois, jour, heures, minutes, maintenant.tm_sec, 0, -1, -1)
        )

    clignote = (time.monotonic() % 0.8) < 0.4
    visible_jour, visible_mois, visible_annee = reglage_date.champs_visibles(mode_date, clignote)
    visible_heures, visible_minutes = reglage_heure.champs_visibles(mode_heure, clignote)
    visible_alarme_heures, visible_alarme_minutes = reglage_heure.champs_visibles(mode_alarme, clignote)

    afficheurs.regler_luminosite(potentiometre.lire_niveau())

    afficheurs.afficher_champ(afficheurs.date_annee, 0, jour, 2, visible_jour)
    afficheurs.afficher_champ(afficheurs.date_annee, 2, mois, 2, visible_mois)
    afficheurs.afficher_separateur(afficheurs.date_annee, 1)
    afficheurs.afficher_champ(afficheurs.date_annee, 4, annee, 4, visible_annee)

    afficheurs.afficher_champ(afficheurs.heure_alarme, 0, heures, 2, visible_heures)
    afficheurs.afficher_champ(afficheurs.heure_alarme, 2, minutes, 2, visible_minutes)
    afficheurs.afficher_separateur(afficheurs.heure_alarme, 1)
    afficheurs.afficher_champ(afficheurs.heure_alarme, 4, alarme_heures, 2, visible_alarme_heures)
    afficheurs.afficher_champ(afficheurs.heure_alarme, 6, alarme_minutes, 2, visible_alarme_minutes)
    afficheurs.afficher_separateur(afficheurs.heure_alarme, 5)

    afficheurs.rafraichir()

    time.sleep(0.02)

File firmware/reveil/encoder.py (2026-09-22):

"""Encodeur rotatif + bouton poussoir associe.

Les annotations de type materiel (rotaryio.IncrementalEncoder,
digitalio.DigitalInOut, microcontroller.Pin) sont en chaines (forward
references) : ces modules ne sont jamais importes au niveau module
(seulement dans depuis_broches(), pour l'usage reel), et les
annotations ne sont de toute facon pas evaluees a l'execution sur
CircuitPython."""


class Encodeur:
    def __init__(self, encodeur_rotatif: "rotaryio.IncrementalEncoder", interrupteur: "digitalio.DigitalInOut") -> None:
        """encodeur_rotatif : objet expose un attribut 'position' (ex. rotaryio.IncrementalEncoder).
        interrupteur : objet expose un attribut 'value', actif a l'etat bas (ex. digitalio.DigitalInOut)."""
        self._encodeur = encodeur_rotatif
        self._sw = interrupteur
        self._position = self._encodeur.position
        self._sw_precedent = True

    @classmethod
    def depuis_broches(
        cls,
        pin_a: "microcontroller.Pin",
        pin_b: "microcontroller.Pin",
        pin_sw: "microcontroller.Pin",
    ) -> "Encodeur":
        """Construit un Encodeur a partir de broches GPIO reelles."""
        import digitalio
        import rotaryio

        encodeur_rotatif = rotaryio.IncrementalEncoder(pin_a, pin_b)
        interrupteur = digitalio.DigitalInOut(pin_sw)
        interrupteur.direction = digitalio.Direction.INPUT
        interrupteur.pull = digitalio.Pull.UP
        return cls(encodeur_rotatif, interrupteur)

    def lire_delta(self) -> int:
        """Retourne le deplacement depuis le dernier appel (0 si pas de rotation)."""
        position = self._encodeur.position
        delta = position - self._position
        self._position = position
        return delta

    def clic(self) -> bool:
        """Retourne True une seule fois par appui sur le bouton (front descendant)."""
        sw_actuel = self._sw.value
        clique = self._sw_precedent and not sw_actuel
        self._sw_precedent = sw_actuel
        return clique

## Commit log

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2026-03-13 un peu plus de composants connectés
    [reveil.kicad_pcb, reveil.kicad_sch]
2026-03-14 tous les composants sont ajoutés et connecté dans le schema
    [date.kicad_sch, heure_alarme.kicad_sch, reveil.kicad_pcb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]
2026-03-15 decoupling caps
    [date.kicad_sch, heure_alarme.kicad_sch, reveil.kicad_pcb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]
2026-03-17 ajout d'un switch pour activer l'alarme
    [reveil.kicad_sch]
2026-03-17 contour du PCB
    [reveil.kicad_pcb]
2026-03-18 all footprints and placements
    [reveil.kicad_pcb, reveil.kicad_sch]
2026-03-18 routing completed
    [reveil.kicad_pcb, reveil.kicad_sch]
2026-03-21 fixed outline
    [reveil.kicad_pcb, reveil.kicad_sch]
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2026-03-22 correction du périmètre
    [reveil.kicad_pcb]
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2026-09-21 Ajout de firmware/requirements.txt (dépendance adafruit_max7219)
    Confirmé par `make deps` (circup) qui installe correctement
    adafruit_max7219 et ses dépendances sur le Pico.
2026-09-21 Exclusion des sorties générées bom/ et jlcpcb/ du dépôt
    Ce sont des exports KiBot dérivés du PCB, comme Generated/ déjà ignoré.
2026-09-21 Mise à jour du layout PCB
    [reveil.kicad_pcb]
2026-09-21 Ajout d'un Makefile firmware (deploy, deps, install-circuitpython)
    deploy, deps et install-circuitpython sont confirmées fonctionnelles
    par test manuel (flash CircuitPython, installation de librairies via
    circup, copie de code.py sur le volume CIRCUITPY).
    test-unit et test-integration sont des cibles stubs qui suivent le
    plan documenté dans le TODO du README ; elles ne sont pas encore
    exécutables tant que le scaffolding de tests n'existe pas.
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2026-09-21 Remplace le stub d'affichage par un blink LED CircuitPython (board.LED)
    Utilise board.LED plutôt qu'une broche GPIO explicite : sur Pico W,
    la LED embarquée est pilotée via la puce wifi et n'est pas câblée
    sur un GPIO direct (GP25 ne fonctionne pas sur ce modèle).
    Confirmé par test manuel : LED clignotante observée sur le Pico W.
2026-09-21 Exclusion de .claude_scratch/ du dépôt
    Répertoire de scratch temporaire de Claude Code, pas du contenu projet.
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2026-09-21 Ajout de requirements-dev.txt pour l'outillage hôte
    Sépare les dépendances pip de la machine de dev (circup, stubs
    CircuitPython pour l'autocomplete) de firmware/requirements.txt qui
    liste les librairies installées sur le Pico via circup (pas un
    fichier pip). kibot n'y figure pas : il nécessite wxPython, sans
    wheel précompilé ici, et s'exécute via le conteneur Docker de la CI
    (commande documentée dans le fichier).
    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
2026-09-21 Met à jour le TODO du README (Makefile fait, séparation des deps)
    Reflète l'état réel : Makefile créé (install-circuitpython, deploy,
    deps ; test-unit/test-integration restent des stubs), deploy copie
    sur le volume CIRCUITPY au lieu de mpremote fs cp (lecture seule sur
    CircuitPython), et séparation firmware/requirements.txt (device) vs
    requirements-dev.txt (hôte). Ajoute une entrée TODO pour évaluer
    Poetry plus tard si le besoin de lockfile reproductible se présente.
2026-09-21 Corrige le pinout du footprint du switch ALARME_ON_OFF1 (court-circuit GND/+3V3)
    Le footprint système Button_Switch_THT:SW_Slide-03_Wuerth-WS-SLTV a
    les pads 1 et 2 physiquement inversés par rapport au composant monté
    (pin 1 attendu à gauche, pin 2 au centre — le footprint avait
    l'inverse). Résultat : selon la position du switch, +3V3 et GND se
    retrouvaient court-circuités via l'interrupteur, faisant chauffer le
    Pico et les câbles d'alimentation.
    Correctif : nouvelle librairie locale reveil.pretty/ avec une copie
    du footprint où seuls les pads 1 et 2 échangent leur géométrie (même
    taille/forme/perçage, juste la position), enregistrée via
    fp-lib-table. Le schéma (ALARME_ON_O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
    [reveil.kicad_pcb, reveil.kicad_sch]
2026-09-21 Ajoute R4 (résistance de base) et corrige R3 pour le circuit LED D1
    GP17 pilotait directement la base de Q1 sans résistance série : la
    broche ne pouvait pas atteindre un état haut propre (chargée par la
    jonction base-émetteur, ~0.6-0.7V), maintenant Q1 en conduction
    partielle constante au lieu de commuter — la LED restait allumée en
    continu, faiblement, au lieu de clignoter.
    - R4 = 1.5 kΩ ajoutée en série entre GP17 et la base de Q1
    (Ib ≈ 1.73 mA pour Ic ≈ 16 mA, marge confortable vs hFE_min du
    2N3904 pour garantir la saturation)
    - R3 = 100 Ω (au lieu de 47K, qui aurait donné ~34 µA, LED quasi
    éteinte) pour ~16 mA dans D1 (LED blanche, Vf≈3.2V supposé),
    enviro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
    [reveil.kicad_sch]
2026-09-21 Place et route R4 sur le PCB (résistance de base LED)
    R4 (1.5 kΩ, ajoutée au schéma dans le commit précédent) est
    maintenant placée et routée sur le PCB. reveil.kicad_sch est
    reformaté par KiCad (réordonnancement interne des blocs, aucun
    changement électrique) suite à la synchronisation schéma/PCB.
    Vérifié par ERC (0 erreur/avertissement) et DRC (0 pad non connecté,
    0 erreur de footprint ; seuls restent des avertissements
    silk_edge_clearance préexistants sur J2, sans rapport avec ce fix).
    Test fonctionnel de la LED pas encore fait : une correction PCB
    supplémentaire est nécessaire avant de pouvoir tester (voir TODO
    README).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
    [reveil.kicad_pcb, reveil.kicad_sch]
2026-09-21 Documente les problèmes matériels trouvés/corrigés et corrige IRF510→IRF540N
    - Corrige la doc : le MOSFET moteur réellement utilisé (Q2) est un
    IRF540N, pas un IRF510 comme documenté jusqu'ici.
    - TODO : documente les deux bugs matériels traités cette session
    (court-circuit switch ALARME_ON_OFF1, circuit LED D1/Q1 sans
    résistance de base) et le fait que le PCB physique existant doit
    encore être corrigé (rework ou nouveau PCB) avant de pouvoir tester
    la LED.
    - TODO : signale un point non corrigé (sur demande) à vérifier avant
    de faire tourner le moteur — Q2 (IRF540N) piloté directement par
    GP18 en 3.3V, sans résistance de grille ni driver ; l'IRF540N n'est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
2026-09-22 Remplace Q2 (IRF510/IRF540N) par un IRLB8721PbF logic-level et ajoute R5
    Le RP2040 pilote la grille de Q2 directement en 3.3V (GP18), et ni
    l'IRF510 (carte physique) ni l'IRF540N (schéma) ne sont des MOSFET
    logic-level (Rds(on) specifie a Vgs=10V) : risque de sous-enhancement
    et d'echauffement. L'IRLB8721PbF est pleinement enhance des 2.5-4.5V,
    compatible avec un pilotage direct en 3.3V.
    Ajoute R5 = 100 ohm en serie entre GP18 et la grille de Q2 pour
    limiter le pic de courant transitoire et amortir le ringing.
    Verifie : pinout G/D/S (broches 1/2/3, meme convention que l'IRF540N),
    footprint TO-220-3_Horizontal_TabDown (corrige apres reperage d'un
    TO-220F errone), ERC (0 violation) et DRC (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
    [reveil.kicad_pcb, reveil.kicad_sch]
2026-09-22 Met à jour README et CLAUDE.md : IRLB8721PbF, Pico W, déploiement firmware
    Le README reflétait encore l'ancien MOSFET (IRF510/IRF540N) et
    l'ancienne topologie de grille non résolue pour Q2 ; corrigé pour
    refléter le remplacement par un IRLB8721PbF + R5 (commit précédent),
    avec un nouveau point de blocage sur le rework physique de la carte.
    Corrige aussi Raspberry Pi Pico -> Pico W (module réellement utilisé
    dans le schéma).
    CLAUDE.md décrivait encore le déploiement comme manuel/sans outillage,
    alors que firmware/Makefile (make deploy/install-circuitpython/deps)
    existe et fonctionne depuis un moment — section réécrite en
    conséquence, avec repository layout et hardware summa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
2026-09-22 Firmware : corrige l'inversion des digits, ajoute les tests unitaires
    Bug corrige : BCDDigits.set_digit()/show_str() de la librairie
    adafruit_max7219 appliquent une inversion de position calculee sur les
    8 digits de la puce entiere, pas sur chaque afficheur logique de 4
    digits separement. Resultat observe : "2026"/"2209" affiches comme
    "6202"/"9022" (DATE et ANNEE inverses ET echanges). Corrige en ecrivant
    directement dans le framebuffer via chip.pixel(), en bypassant cette
    inversion (display.py : _ecrire_digit).
    Ajoute les tests unitaires (pytest, TDD - tests ecrits avant
    l'implementation a chaque etape) :
    - reglage_date.py extrait en module pur (sans import CircuitPython) :
    jours_dans_m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
    [code.py, display.py, encoder.py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]
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2026-09-22 Firmware : ajoute des annotations de type (PEP 484)
    Modules purs (reglage_date.py, reglage_heure.py) : annotations
    standard sur les fonctions (int/str/bool/Tuple), typing importe dans
    un try/except ImportError (CircuitPython n'embarque pas forcement le
    module typing).
    Modules materiels (display.py, encoder.py, luminosite.py) : les types
    CircuitPython (BCDDigits, IncrementalEncoder, DigitalInOut, AnalogIn,
    microcontroller.Pin) sont annotes en chaines (forward references),
    sans jamais etre importes au niveau module - seulement dans
    depuis_broches()/depuis_broche(), pour l'usage reel. Deux raisons :
    1) CircuitPython n'evalue de toute facon jamais les annotations a
    l'execution (confirme par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
    [code.py, display.py, encoder.py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]
2026-10-03 README : ajoute les améliorations issues de la revue schéma/PCB et les points de test proposés
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2026-10-03 Schéma/PCB : remplace le symbole des afficheurs CA56-12EWA par CC56-12EWA
    Le schéma utilisait un symbole à anode commune alors que le câblage
    (anodes communes CA1-CA4 vers les sorties DIG_x du MAX7219, qui
    absorbent le courant) n'a de sens qu'avec des afficheurs à cathode
    commune. Comme le circuit fonctionne, les composants montés sont bien
    des CC56-12EWA.
    Remplace le symbole dans date.kicad_sch et heure_alarme.kicad_sch (les
    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
    [date.kicad_sch, heure_alarme.kicad_sch, reveil.kicad_pcb]
2026-10-03 Schéma/PCB : ajoute la diode de roue libre et le snubber du moteur
    Rien ne protégeait le drain de Q2 contre la surtension inductive à la
    coupure du moteur M1 (roue libre) : l'avalanche de Q2 absorbait
    l'énergie et parasitait le 5 V du Pico.
    Ajoute en parallèle de M1, entre le drain de Q2 et VBUS :
    - D2 (Schottky 1N5819), cathode côté VBUS, anode côté drain de Q2
    - C5 (100 nF) contre les parasites de commutation des balais du moteur
    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
    [date.kicad_sch, heure_alarme.kicad_sch, reveil.kicad_pcb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]
2026-10-03 Schéma/PCB : ajoute les pull-down de grille Q2 et de base Q1
    GPIO18 est en haute impédance pendant le boot/reset du Pico. Sans rien
    pour fixer son potentiel, la grille de Q2 pouvait flotter à un niveau
    intermédiaire (vibration intempestive du moteur, ou Q2 à moitié
    passant qui chauffe), et la base de Q1 pouvait aussi flotter et le
    faire conduire légèrement, ce qui aurait pu repousser du courant vers
    la grille de Q2 à travers R5.
    Ajoute :
    - R6 (100 kΩ) entre la grille et la source de Q2 (donc vers GND,
    Source étant déjà relié à GND)
    - R7 (47 kΩ) entre la base et l'émetteur de Q1, pour garder Q1
    déterministement bloqué pendant que sa base flotte
    Empreintes placées et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
    [reveil.kicad_pcb, reveil.kicad_sch]
2026-10-03 Schéma/PCB : fixe la valeur de R1 (ISET de U2) à 47 kΩ
    R1 avait la valeur placeholder « R » au lieu d'une vraie valeur. C'est
    la résistance ISET de U2 (MAX7219 pilotant HEURE/ALARME) : sans valeur
    correcte, HEURE/ALARME n'auraient pas la même luminosité que
    DATE/ANNEE (pilotés par U1, dont R2 = 47 kΩ).
    Aligne R1 sur R2 (47 kΩ, ≈ 14 mA par segment) dans heure_alarme.kicad_sch
    et sur le PCB. ERC/DRC revérifiés via le conteneur Docker KiBot :
    0 erreur/avertissement ERC, DRC inchangé (6 avertissements
    silk_edge_clearance préexistants sur J2).
    [heure_alarme.kicad_sch, reveil.kicad_pcb]
2026-10-03 Schéma/PCB : unifie D2 sur 1N5822 pour simplifier la BOM
    D2 (roue libre moteur) était en 1N5819 (1A). Passe en 1N5822 (3A) pour
    n'avoir qu'une seule référence de Schottky dans tout le projet : la
    diode prévue pour protéger VSYS contre le retour du jack J1 (section
    Alimentation du README) sera aussi une 1N5822, choisie avec de la
    marge faute de datasheet pour le courant moteur réel.
    Même boîtier DO-41 THT, même tension inverse (40V), même datasheet
    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
    [reveil.kicad_pcb, reveil.kicad_sch]
2026-10-04 Schéma/PCB : isole VBUS du jack J1, alimente le reste de la carte via VSYS
    Le jack J1 alimentait directement le net VBUS, partagé avec la broche VBUS
    du Pico : branché en même temps que l'USB, les deux 5 V se retrouvaient en
    parallèle et le jack pouvait renvoyer du courant vers le PC.
    Ajoute D3 (Schottky 1N5822, même référence que D2) entre le jack et un
    nouveau rail renommé VSYS, plus C6 (220 µF) en entrée. Tout ce qui était
    sur VBUS (MAX7219 U1/U2, moteur, LED, D2) passe sur VSYS, qui alimente le
    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
    [date.kicad_sch, heure_alarme.kicad_sch, reveil.kicad_pcb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]
2026-10-04 README : coche le TODO PCB sur la distance Pico-Q2 du VIBREUR
    R5 (résistance de grille) et R6 (résistance de rappel grille-source,
    ajoutée depuis avec la correction de la grille flottante) sont déjà
    toutes les deux proches de Q2 sur le PCB (~20 mm et ~5.5 mm). Les ~169 mm
    ne concernent que le signal GP18 brut entre le Pico et R5, sans caractère
    critique.
2026-10-04 Schéma/PCB : découple LUMINOSITE et l'alimente depuis ADC_VREF
    Ajoute C7 (100 nF) sur le curseur du potentiomètre LUMINOSITE1, et
    reconnecte le haut du pont diviseur sur la broche ADC_VREF du Pico
    (auparavant non connectée) au lieu de +3V3, pour une référence ADC plus
    propre.
    Met à jour le README : coche ce point, et marque le bouton reset et les
    filtres RC des encodeurs comme des décisions explicites (pas voulus /
    pas nécessaires pour l'instant) plutôt que des TODO ouverts.
    [reveil.kicad_pcb, reveil.kicad_sch]
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
